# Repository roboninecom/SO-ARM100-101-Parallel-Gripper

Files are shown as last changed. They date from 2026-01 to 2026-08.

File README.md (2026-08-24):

# SO-ARM100/101 Parallel Gripper

<div align="center">

SO-ARM101 Parallel Gripper (https://youtube.com/shorts/bSyXjgNGXZk)

**🎥 [Watch the gripper in action!](https://youtube.com/shorts/bSyXjgNGXZk)**

A lightweight 3D-printed parallel gripper designed by **[Robonine](https://robonine.com)** for the open-source SO-ARM100/101 robotic platform.







---

**Questions? We're here to help!**
📩 Email: [hello@robonine.com](mailto:hello@robonine.com)

</div>

---

## ✨ Key Features

| Feature | Description |
|---|---|
| **120N Gripping Force** | Reliable parallel jaw mechanism |
| **14 mm/s Speed** | Gripper operation speed |
| **84mm Full Stroke** | Wide opening for various objects |
| **0.5mm Repeatability** | High precision positioning |
| **Camera Compatible** | Supports RealSense, Orbbec, USB cameras |
| **3D Printable** | All parts print on standard FDM printers |
| **~$62 Total Cost** | Affordable open-source solution |
| **Easy Assembly** | 30-45 minutes with basic tools |

---

## 📸 Gallery

<div align="center">

### Gripper on SO-ARM101

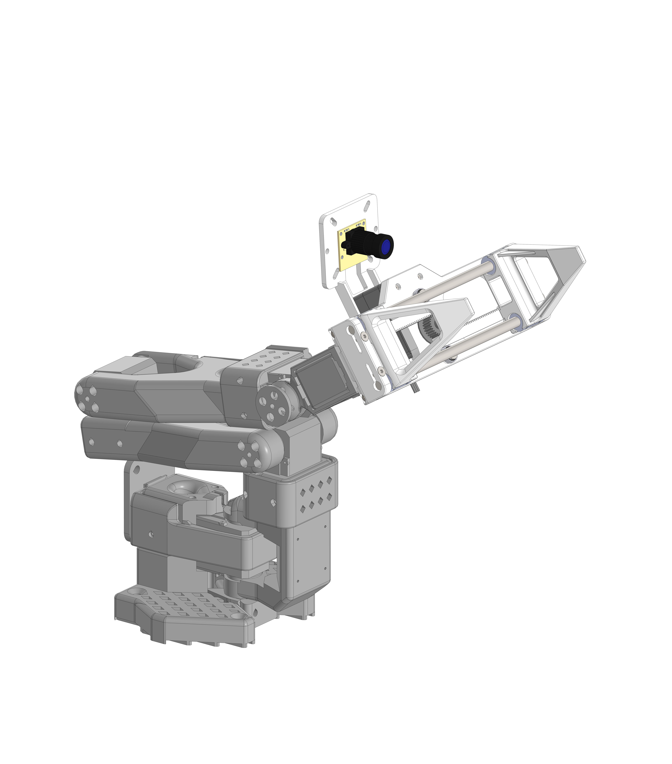
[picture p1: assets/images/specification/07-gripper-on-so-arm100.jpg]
Gripper mounted on SO-ARM101


*Follower gripper integrated with SO-ARM101 robot arm*

### Dimensions

Gripper dimensions

*128 × 109 × 130.5 mm, full stroke 84 mm*

</div>

---

## 📋 Specifications

### Gripper Parameters

| Parameter | Value |
|---|---|
| Maximum gripping force | **120 N** |
| Maximum gripping speed | **14 mm/s** |
| Full stroke | **84 mm** |
| Repeatability | **0.5 mm** |
| Assembly mass (PLA, 30% infill) | **170 g** |
| DOF | **1** |

### Dimensions

| Dimension | Value |
|---|---|
| Width | 128 mm |
| Depth | 130.5 mm |
| Height | 109 mm |

### Servo Parameters (Feetech STS3215)

| Parameter | Value |
|---|---|
| Operating Voltage | 12V |
| Stall torque | 30 kg·cm |
| Speed (no load) | 45 RPM |
| Encoder | Absolute magnetic 12-bit |
| Protocol | RS485/TTL up to 1 Mbps |
| Operating temperature | -20°C ~ 60°C |

---

## 📷 Camera Compatibility

The gripper supports multiple cameras via interchangeable camera holder:

| Camera | Type | Use Case |
|---|---|---|
| IMX335 5MP USB | RGB | Basic vision tasks |
| GC2093 2MP USB | RGB | Budget option |
| Orbbec Gemini 2 | RGB-D | 3D perception |
| RealSense D405 | RGB-D | Close-range depth |
| RealSense D435/D435i | RGB-D | General purpose |
| RealSense D455 | RGB-D | Long-range depth |

<div align="center">

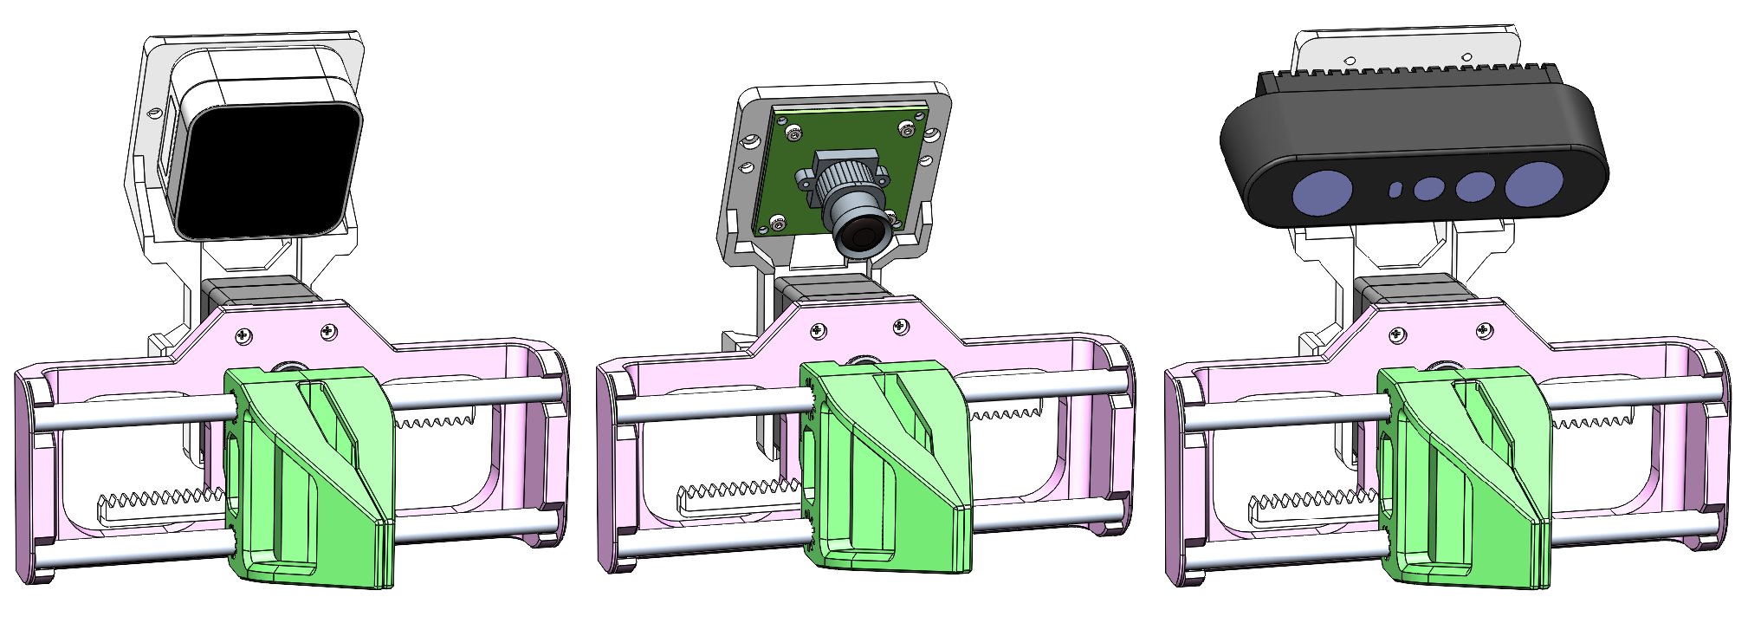
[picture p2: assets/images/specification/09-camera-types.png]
Different cameras mounted on gripper


*RealSense, USB camera module, Orbbec Gemini 2*

</div>

---

## 💰 Bill of Materials

**Total Cost: ~$62** ([Full BOM with Amazon links](docs/bom.md))

| Category | Components | Est. Cost |
|---|---|---|
| Electronics | Feetech STS3215 Servo + Servo Bus Adapter | ~$40 |
| Bearings | MF106ZZ (x2) | ~$2 |
| Aluminium/Carbon Tubes | D6x1×125mm (x2) | ~$4 |
| 3D Printing | 8 parts (~100-150g PLA) | ~$12 |
| Fasteners | M2/M4 screws, M2 nuts, M3 set screws | ~$3 |

---

## 🚀 Quick Start

### 1. Print the Parts (2-4 hours)

Download STL files from [`models/parts/`](models/). Compatible with popular printers like **Bambu Lab A1 mini**, **Prusa MINI+**, and any printer with ≥180×180mm bed.

| Part | Qty | Settings |
|---|:---:|---|
| Main frame (RB9.01.062.010) | 1 | 20% infill |
| Clamp (RB9.01.062.020) | 2 | 20% infill |
| Gear rack (RB9.01.062.030) | 2 | 100% infill |
| Gear (RB9.01.062.040) | 1 | 100% infill |
| Camera holder (RB9.01.060.074) | 1 | 20% infill |
| Holder (RB9.01.060.080) | 1 | 20% infill |
| Camera Spacer (RB9.01.060.090) | 1 | 20% infill |
| D405 holder (RB9.01.060.110) | 1 | 20% infill |

### 2. Order Components (1-2 days)

See [Bill of Materials](docs/bom.md) for direct Amazon links.

### 3. Assemble (30-45 minutes)

Follow the [Assembly Guide](docs/assembly-guide.md) with step-by-step images:

1. Mount gear on servo disc, install this assembly on servo
2. Insert servo cable
3. Using Feetech software move servo to its minimal position (move the slider in the software to the left)
4. Attach gear racks to clamps
5. Inserts the rods into both clamps
6. Install bearings on main frame and fix with srews
7. Snap the rods into the frame
8. Spread the clamps to the extreme positions on the left and right
9. Insert servo and fix it with screws
10. Attach Camera Spacer and UVC camera, fix with 4x screws and nuts M2 (optional)
11. Mount to robot arm (optional)

### 4. Software

```bash
# Configure servo motor if necessary
https://lab.robonine.com/tools/robonine/feetech-bus

# Control gripper
https://lab.robonine.com/tools/robonine/control-robot
```

---

## 📁 Repository Structure

```
├── assets/
│   └── images/
│       ├── assembly/          # Assembly step images
│       └── specification/     # Technical drawings
├── docs/
│   ├── assembly-guide.md                # Step-by-step assembly
│   ├── bom.md                           # Bill of materials with links
│   ├── Parallel gripper by Robo9.pdf    # Gripper product specification
│   ├── quick-start.md                   # Getting started guide
│   ├── SO-ARM101 by Robo9.pdf           # SO-ARM101 product specification
│   └── specifications.md               # Technical specifications
├── models/
│   ├── parts/                                    # Individual STL files
│   └── Follower gripper (165x165 bed size).STL   # Complete assembly (165×165mm bed)
├── community/
│   └── histology-slide-gripper/   # Community variant (CAD, MuJoCo model)
├── simulation/
│   ├── README.md                  # Simulation overview
│   ├── gazebo/                    # Gazebo guide
│   ├── mujoco/                    # MuJoCo guide
│   ├── webots/                    # Webots guide
│   ├── coppeliasim/               # CoppeliaSim guide
│   ├── isaac_sim/                 # Isaac Sim guide
│   └── so_arm_101_description/    # ROS2 package (URDF, launch, Docker)
├── software/
│   └── python/                # Control software
├── examples/                  # Usage examples
├── HARDWARE-LICENSE.txt       # CERN-OHL-P-2.0 (CAD, geometry)
├── SOFTWARE-LICENSE.txt       # Apache-2.0 (code)
├── DOCS-LICENSE.txt           # CC BY 4.0 (docs, images)
├── LICENSING.md               # Which licence covers what
├── NOTICE                     # Third-party attribution
├── REUSE.toml                 # Machine-readable licence map
├── RELICENSING.md             # Record of the 2026 relicensing
└── CONTRIBUTING.md
```

---

## 📖 Documentation

| Document | Description |
|---|---|
| [Quick Start Guide](docs/quick-start.md) | Get running in 30 minutes |
| [Assembly Guide](docs/assembly-guide.md) | Step-by-step with images |
| [Gripper Assembly Guide (PDF)](docs/Assembly%20Guide%20Follower%20Gripper.pdf) | Printable gripper assembly instructions |
| [SO-ARM101 Assembly Guide (PDF)](docs/Assembly%20Guide%20SO-ARM101.pdf) | Full SO-ARM101 arm assembly instructions |
| [Bill of Materials](docs/bom.md) | Parts list with Amazon links |
| [Specifications](docs/specifications.md) | Technical details |
| [3D Models](models/README.md) | Print settings and files |
| [Parallel Gripper Product Spec (PDF)](docs/Parallel%20gripper%20by%20Robo9.pdf) | Parallel gripper product specification by Robo9 |
| [SO-ARM101 Product Spec (PDF)](docs/SO-ARM101%20by%20Robo9.pdf) | SO-ARM101 robot arm product specification by Robo9 |

---

## 🔧 Hardware Requirements

### Electronics
- 1× Feetech STS3215 Servo Motor
- 1× Bus Servo Adapter Board (Waveshare)

### Mechanical
- 2× MF106ZZ Bearings (6×10×3 mm)
- 2× Aluminium/Carbon Tubes D6x1×125 mm

### Fasteners
- 2× M4×8 DIN 7991 screws
- 4x M2x8 DIN 912 screws
- 4× M2 DIN 934 nuts
- 4× M3×4 DIN 913 set screws

### Tools Required
- Phillips head screwdriver (PH1)
- Hex keys M2 (H1.5) and M4 (H2.5)

---

## 🖥️ Simulation

The SO-ARM101 can be simulated in 5 physics engines using a ROS2 description package with a single parameterized URDF. No ROS2 installation required -- Docker handles everything.

<div align="center">

| Gazebo (Ignition Fortress) | MuJoCo |
|:-:|:-:|
| SO-ARM-101 in Gazebo | SO-ARM-101 in MuJoCo |

</div>

| Simulator | Status | Docker |
|---|---|---|
| [Gazebo](simulation/gazebo/README.md) | Ready | `docker compose run gazebo` |
| [MuJoCo](simulation/mujoco/README.md) | Ready | `docker compose run mujoco` |
| [Webots](simulation/webots/README.md) | Unstable | `docker compose run webots` |
| [CoppeliaSim](simulation/coppeliasim/README.md) | Not tested | External simulator |
| [NVIDIA Isaac Sim](simulation/isaac_sim/README.md) | Not tested | External simulator |

**Quick start (Docker):**

```bash
cd simulation/so_arm_101_description
docker compose run gazebo    # or mujoco, webots
```

See the [Simulation Guide](simulation/README.md) for full setup, architecture details, and robot commanding.

---

## 🔬 Community Mods

Variants of the gripper built by the community, each self-contained in [`community/`](community/):

| Mod | Author | Description |
|-----|---|---|
| [Histology Slide Gripper](community/histology-slide-gripper/) | [Michael Viacheslavov](https://github.com/histochemichael) | Clamps for 75 x 25 mm microscope slides and staining dippers/racks, plus an angled Arducam holder for monitoring the grasp. |

<div align="center">

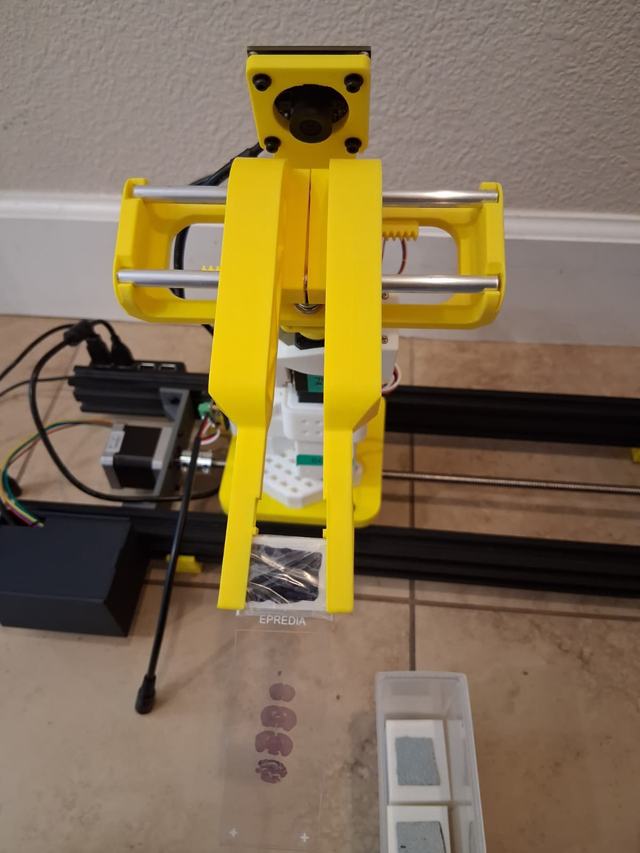
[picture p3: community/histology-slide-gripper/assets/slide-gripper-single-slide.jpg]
Histology slide gripper mod holding a microscope slide


*Histology Slide Gripper mod — click for full description, CAD files, and demo*

</div>

---

## 🤝 Contributing

We welcome contributions! Please feel free to:
- 🐛 Report bugs and issues
- 💡 Suggest new features
- 🔧 Submit pull requests
- 📖 Improve documentation

---

## 📄 License

Copyright (c) 2025 Robonine. This project is multi-licensed — different kinds of
material carry different licences:

| Material | Licence |
|---|---|
| Hardware designs — `models/`, community CAD, gripper meshes | [CERN-OHL-P-2.0](HARDWARE-LICENSE.txt) |
| Software — `software/`, `examples/`, `simulation/`, simulation code in `community/` | [Apache-2.0](SOFTWARE-LICENSE.txt) |
| Documentation and images — `docs/`, `assets/`, all `README.md` | [CC BY 4.0](DOCS-LICENSE.txt) |

See [`LICENSING.md`](LICENSING.md) for the exact file-by-file map and
[`REUSE.toml`](REUSE.toml) for the machine-readable version.

**Not everything here is Robonine's work.** The SO-ARM101 arm meshes are derived
from [TheRobotStudio's upstream project](https://github.com/TheRobotStudio/SO-ARM100)
and remain Apache-2.0; the histology slide gripper was contributed by
[@histochemichael](https://github.com/histochemichael). See [`NOTICE`](NOTICE)
before reusing any mesh.

Releases up to and including `v0.3.1` were published under GPL-3.0 and remain
available under those terms — see [`RELICENSING.md`](RELICENSING.md).

---

## 🔗 Links

- [Feetech STS3215 Servo](https://www.feetechrc.com/525603.html)
- [Waveshare Bus Servo Adapter](https://www.waveshare.com/bus-servo-adapter-a.htm)
- [STServo Python SDK](https://github.com/FEETECH-RC/STServo_SDK_Python)

---

## 👥 Engineering Team

| Name | Role | Contact |
|---|---|---|
| **Boris Kotov** | Software Engineer | [Telegram](https://t.me/bkotov) |
| **Alan Subin** | Design Engineer | [LinkedIn](https://www.linkedin.com/in/alan-subin/) |

---

<div align="center">

**Built for the robotics community by [Robonine](https://robonine.com)** 🤖

**Questions? We're here to help!**
📩 Email: [hello@robonine.com](mailto:hello@robonine.com)

</div>

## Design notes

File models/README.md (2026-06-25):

# 3D Models

This folder contains STL files for the Follower Gripper assembly.

## Complete Assembly

| File | Description | Compatible Printers |
|---|---|---|
| `Follower gripper (165x165 bed size).STL` | Complete gripper parts kit | Printers with bed size > 165×165mm |

### Compatible 3D Printers

- **Bambu Lab A1 mini** (180×180×180mm)
- **Prusa MINI / MINI+** (180×180×180mm)
- **Creality Ender-2 Pro** (165×165×180mm)
- **Anycubic Kobra Neo** (220×220×250mm)
- **Artillery Genius** (220×220×250mm)

*Note: Any printer with bed size ≥165×165mm can print the complete assembly preview.*

## Individual Parts

Located in the `parts/` folder:

| Part Number | File | Qty | Description |
|---|---|:---:|---|
| RB9.01.060.074 | `Camera holder.STL` | 1 | Camera mounting bracket |
| RB9.01.060.080 | `Holder.STL` | 1 | Mounting bracket without camera |
| RB9.01.060.090 | `Camera spacer.STL` | 1 | Spacer for camera |
| RB9.01.060.110 | `D405 holder.STL` | 1 | Holder for D405 camera |
| RB9.01.062.010 | `Main frame.STL` | 1 | Main structural frame |
| RB9.01.062.021 (D6.0) | `Clamp.STL` | 2 | Finger clamps |
| RB9.01.062.021 (D6.1) | `Clamp.STL` | 2 | Finger clamps |
| RB9.01.062.021 (D6.2) | `Clamp.STL` | 2 | Finger clamps |
| RB9.01.062.021 (D6.3) | `Clamp.STL` | 2 | Finger clamps |
| RB9.01.062.031 | `Gear rack.STL` | 2 | Gear racks for linear motion |
| RB9.01.062.040 | `Gear.STL` | 1 | Drive gear |
| RB9.01.062.100 | `Nail.STL` | 2 | Nails |

## Print Settings

| Parameter | Recommended Value |
|---|---|
| Material | PLA / PETG |
| Layer Height | 0.2mm (0.15mm for gears) |
| Infill | 20% (30% for gears) |
| Supports | As needed |
| Walls | 3-4 perimeters |

## Notes

- Print gears with higher infill (100%) for better strength
- Main frame may require supports depending on orientation
- Post-processing: light sanding may be needed for bearing fits
- Individual parts can be printed on any standard FDM printer

## Better rods fit
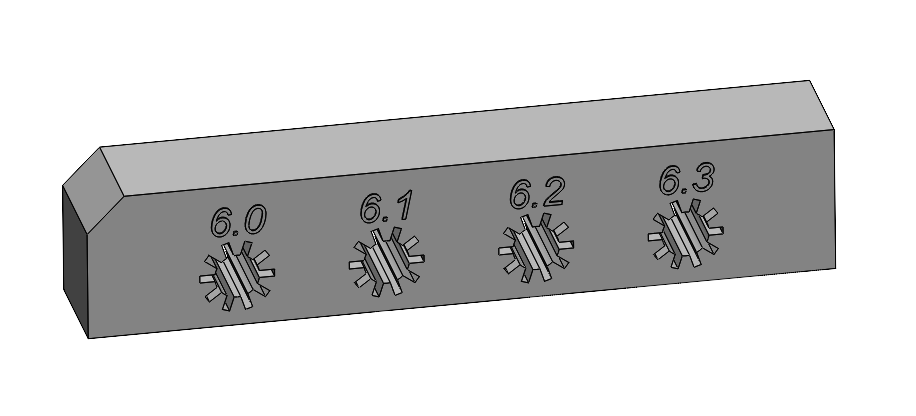
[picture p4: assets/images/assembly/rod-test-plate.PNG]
Test plate


To ensure the rods you purchase fit better into the clamps, you need to use a test piece. Print it and, working from the largest hole to the smallest, select the diameter that allows the rod to fit into the test part without difficulty and with minimal clearance. Then print clamps with the same hole diameter which is mentioned in stl file name (e.g. RB9.01.062.021 (D6.1) if you choose diameter 6.1 mm).

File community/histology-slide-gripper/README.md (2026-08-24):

# Histology Slide Gripper (Community Mod)

A community variant of the SO-ARM100/101 Parallel Gripper by [Michael Viacheslavov](https://github.com/histochemichael), adapted for histology and histotechnology automation: gentle pickup of standard 75 x 25 mm microscope slides, slide staining dippers/racks, and a close camera view of the grasp.

<div align="center">

Histology slide gripper demo

*SO-ARM100/101 parallel gripper using the custom clamps to handle microscope slides and a staining dipper/rack.*

</div>

## What Changed vs. the Base Gripper

| Addition | Description |
|---|---|
| Microscope slide clamps | Long, flat clamp geometry supports direct pickup of standard 75 x 25 mm microscope slides. |
| Slide rack/dipper handling | Clamp spacing and tips engage slide staining dippers/racks like the Medicus Health slide staining dipper linked below. |
| Angled Arducam holder | A printable holder aims an Arducam global-shutter USB camera at the gripper jaws for close-up monitoring of slide and rack pickup. |
| Complete assembly CAD | A full printable STL and editable STEP assembly are in [`cad/`](cad/). |

## Gallery

<div align="center">

| Single slide pickup | Staining dipper/rack pickup | Arducam holder view |
|:-:|:-:|:-:|
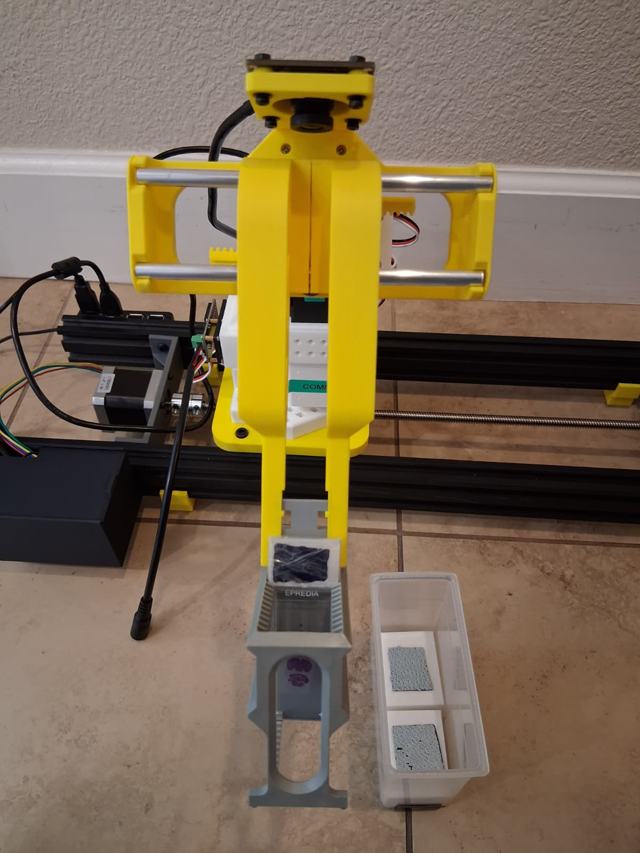
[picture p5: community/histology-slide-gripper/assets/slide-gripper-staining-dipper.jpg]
Clamp aligned with slide staining dipper
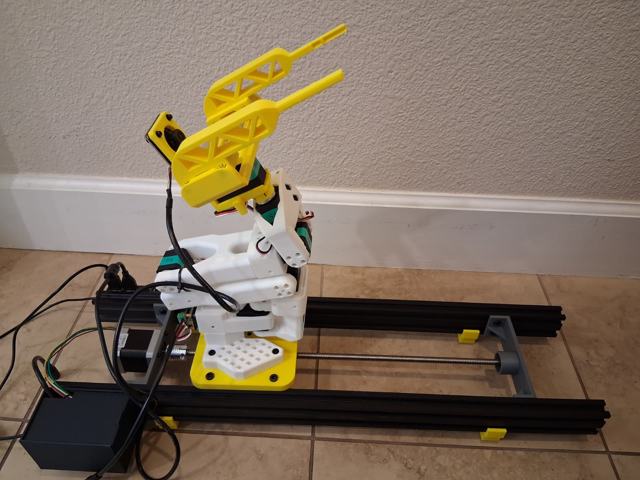
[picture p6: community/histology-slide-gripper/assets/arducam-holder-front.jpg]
Arducam holder above the gripper jaws
| Clamp holding a microscope slide |  |  |

| Front view | Jaw geometry | Isometric assembly |
|:-:|:-:|:-:|
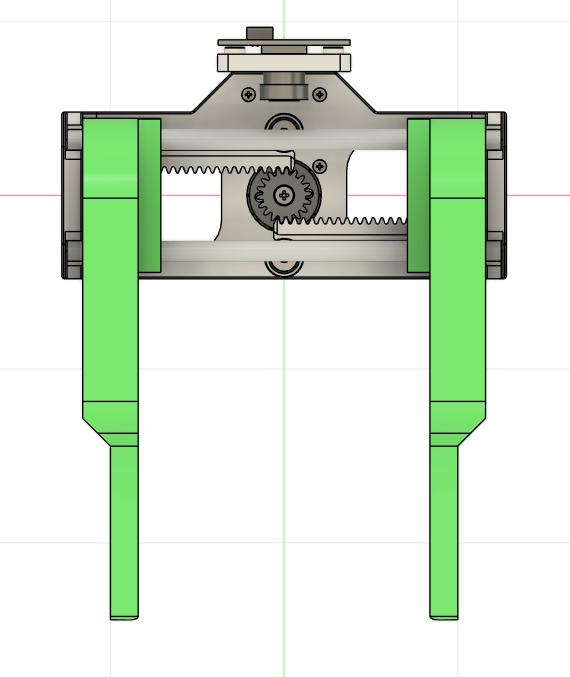
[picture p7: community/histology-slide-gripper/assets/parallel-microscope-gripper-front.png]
Front CAD view of the microscope slide gripper mod
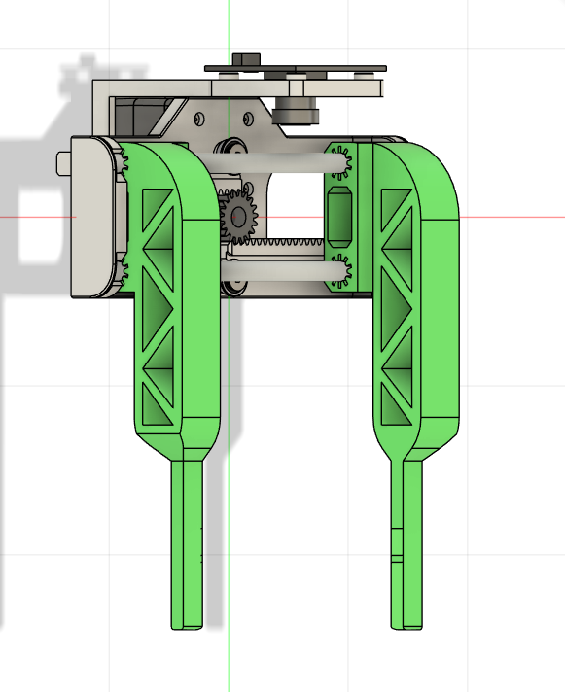
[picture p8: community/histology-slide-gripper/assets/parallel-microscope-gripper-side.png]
Angled CAD view showing the microscope slide jaw geometry
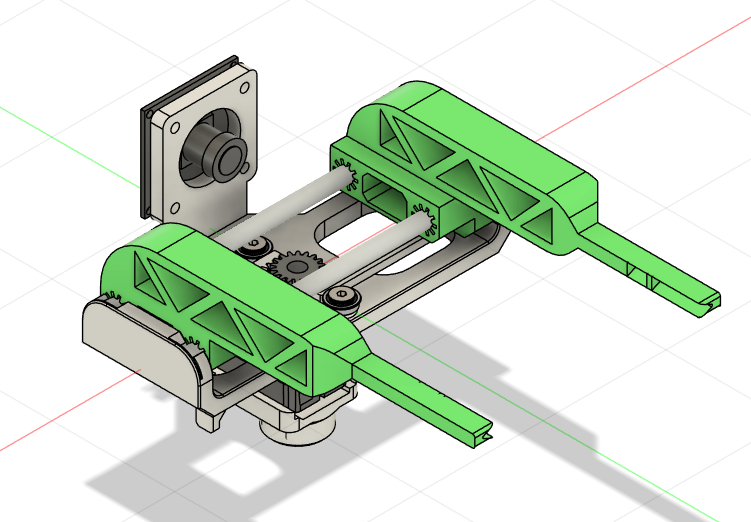
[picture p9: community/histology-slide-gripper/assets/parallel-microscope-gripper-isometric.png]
Isometric CAD view of the full microscope slide gripper assembly
|  |  |  |

</div>

## CAD Files

| File | Format | Use |
|---|---|-----|
| [`cad/the-parallel-microscope-slide-gripper.stl`](cad/the-parallel-microscope-slide-gripper.stl) | STL | Printable full assembly for the microscope slide gripper mod. |
| [`cad/the-parallel-microscope-slide-gripper.step`](cad/the-parallel-microscope-slide-gripper.step) | STEP | Editable CAD source for the full assembly. |

## Add-on Bill of Materials

These items are specific to the slide/rack workflow and are not part of the base gripper [BOM](../../docs/bom.md).

| Component | Qty | Notes | Link |
|---|:---:|---|---|
| Arducam 100fps Mono Global Shutter USB Camera, OV9281 | 1 | Camera used with the angled holder to watch slide and rack pickup near the jaws. | [Amazon UK](https://www.amazon.co.uk/Arducam-Shutter-Distortion-Computer-Raspberry/dp/B0FXWWF55X) |
| Slide Staining Plastic Dipper with Handle | 1+ | Reference staining dipper/rack target; designed for standard 75 x 25 mm slides. | [Medicus Health](https://www.medicus-health.com/slide-staining-dipper.html) |
| Parallel microscope slide gripper assembly | 1 | Print `the-parallel-microscope-slide-gripper.stl`; STEP file is included for edits. | [`cad/`](cad/) |

## MuJoCo Simulation

<div align="center">

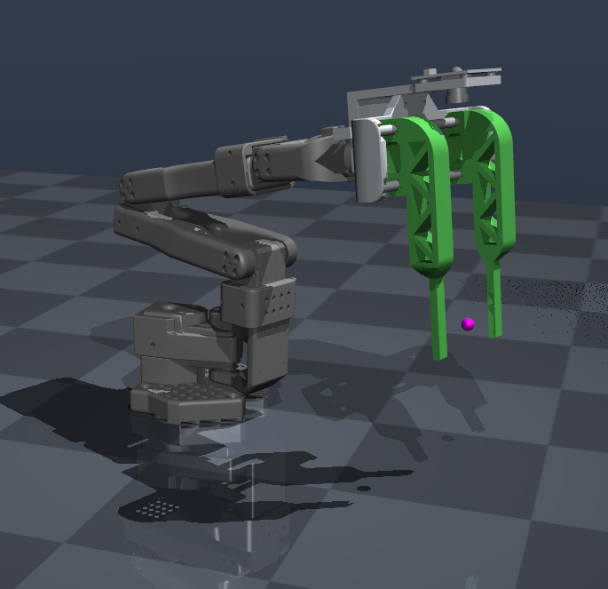
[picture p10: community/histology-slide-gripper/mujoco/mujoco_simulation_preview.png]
SO-ARM101 histology slide gripper running in MuJoCo


*SO-ARM101 with the histology slide gripper mounted and running in MuJoCo.*

</div>

A self-contained MuJoCo 3.4.0 model is available in [`mujoco/`](mujoco/). It includes the full SO-ARM101 model, gripper meshes, a standalone gripper testbench, build scripts, and a headless grasp-and-lift check.

From the repository root:

```bash
conda activate lerobot
cd community/histology-slide-gripper/mujoco
python -m pip install -r requirements.txt
python view.py
```

Use the `sg_grip` control in the MuJoCo viewer to open and close the jaws. See the [simulation README](mujoco/README.md) for model details, controls, validation, and rebuilding instructions.

## Notes

- The gripper fingers are intended for standard 75 x 25 mm microscope slides and slide staining dippers/racks.
- The assembly keeps the camera view aimed toward the gripper jaws so the camera can observe slide and rack pickup.
- Test with non-critical slides first and tune print material, infill, and gripper force for your workflow.

## Links

- 🎥 [Demo: slide and staining rack pickup (LinkedIn)](https://www.linkedin.com/posts/michael-viacheslavov_histology-histotechnology-robotics-ugcPost-7482570199859240960-Gqpw/)

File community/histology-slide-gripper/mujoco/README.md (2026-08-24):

# Microscope Slide Gripper in MuJoCo

The SO-ARM101 with the histology slide parallel gripper, exported from Fusion and mounted in place of the stock Robo9 clamps.

Tested with `mujoco` 3.4.0 in the `lerobot` conda environment. No ROS 2 or Docker is required.

```bash
conda activate lerobot
cd community/histology-slide-gripper/mujoco
python -m pip install -r requirements.txt
python view.py                      # full arm + slide gripper
python view.py scene_gripper.xml    # gripper alone on a testbench
python test_grasp.py                # headless grasp-and-lift check -> grasp_check.png
```

## MuJoCo simulation preview

SO-ARM101 histology slide gripper running in MuJoCo

This scene shows the SO-ARM101 with the histology slide parallel gripper mounted on
the wrist, using the same MuJoCo model launched by:

```bash
conda activate lerobot
cd community/histology-slide-gripper/mujoco
python view.py
```

## What is modelled

| Link | Source | Mass |
|---|---|---|
| `slide_gripper_base` | main frame, STS3215, guide rods, bearings, camera holder, Arducam OV9281 | 0.20 kg |
| `sg_jaw_right` / `sg_jaw_left` | RB9.01.062.020 clamp + RB9.01.062.030 rack (m0.8) | 0.035 kg each |
| `sg_pinion` | RB9.01.062.040 involute gear, 18 T, 0.8 module | 0.008 kg |

Kinematics taken from the as-built joints in the Fusion assembly
(`Slide_Jaw_Right`, `Slide_Jaw_Left`, `Drive_Pinion`), which are self-consistent:
the 18 T / 0.8 module pinion has a 7.2 mm pitch radius, and 7.2 mm x 4.9306 rad =
**35.5 mm** of rack travel per jaw — exactly the slider limits in the CAD.

## Control

One actuator, `sg_grip`, commanded in **metres of jaw travel**:

| `ctrl` | jaw travel | aperture between the blade faces |
|---|---|---|
| `0.0` | 0 mm | **84 mm** (fully open) |
| `0.0295` | 29.5 mm | 25 mm (a microscope slide) |
| `0.0355` | 35.5 mm | **13 mm** (fully closed) |

Both jaws are driven from the single pinion, so `sg_jaw_left_joint` and
`sg_pinion_joint` are slaved to `sg_jaw_right_joint` by `<equality>` constraints —
the gear visibly turns with the jaws. Command *past* the object to get squeeze:
closing onto a 25 mm object with `ctrl=0.0355` gives about 4.7 N at the pads.

The five arm joints keep their URDF names (`base_link_to_link1` ... `link4_to_link5`).

## Collision geometry

Mesh geoms are **visual only** (`contype=0`), because MuJoCo convex-hulls meshes and
the hull of an L-shaped jaw fills the gap you are trying to grip with. Contact is
carried by boxes on the two gripping surfaces of each jaw (group 3, hidden in the
renders):

- `sg_pad_*` — the 30 mm slide blade, CAD x 42–50, z 26–31
- `sg_mid_*` — the wider mid-section, CAD x 42–58, z 18.5–38.5

The TCP site `sg_tcp` sits between the blades; `sg_camera` is the Arducam optical frame.

## Files

- `so101_slide_gripper.xml` — the full robot (generated by `build_full.py`)
- `scene_gripper.xml` — gripper alone, with a lift axis for testing
- `gripper_assets.xml` / `gripper_body.xml` / `gripper_actuation.xml` — the gripper,
  as includes usable from both degree- and radian-unit models
- `meshes/{base,jaw_right,jaw_left,pinion}.stl` — exported from Fusion in **assembly
  coordinates**, so every part is already in its correct place (no per-part origins to chase)
- `meshes/arm/` — arm meshes from the Robo9 repo
- `build_arm.py` — strips xacro from `so_101.urdf.xacro`, drops the stock clamps, compiles to MJCF
- `build_full.py` — grafts the gripper onto `link5`; **edit `MOUNT_POS`/`MOUNT_QUAT` here**

## How the gripper was located on the wrist

`link5_1.stl` in the Robo9 repo is not just the wrist — it contains the entire stock
gripper (frame, guide rods, camera). So it is the part the slide-gripper design replaces, and
`build_full.py` deletes its mesh and drops its mass from 0.556 kg to 0.08 kg.

The mount pose was solved, not guessed: `base.stl` was fitted against
`link5_1.stl` over the geometry they share (main frame + guide rods) by searching all
24 axis-aligned rotations and scoring nearest-neighbour distance. Best fit is
**+90 deg about X** (CAD +Y -> link5 +Z, CAD +Z -> link5 -Y) with a 2.0 mm median
residual — the slide clamps hang perpendicular to Robo9's pointed clamps, matching
the Fusion assembly.

## Stability

The model settles to `max|qvel| = 0` and stays there. If you ever see it shake, the
first thing to check is stray contacts (`ncon` in the viewer's info panel should be 0
with the arm at rest). Three things were needed:

1. **`<exclude body1="world" body2="link1_1"/>`** - the real fix. The URDF importer
   merges `base_link` into `worldbody`, and MuJoCo skips parent/child collisions
   *except* when the parent is the world body. So the base mesh and link1 mesh
   interpenetrated at the shoulder, producing a permanent contact that pinned the yaw
   actuator at its +-1.5 N.m limit. This alone took settled `|qvel|` from 4.78 to 0.
2. `sg_pinion_joint` armature 1e-6 -> **1e-4**. A joint slaved by a stiff equality with
   almost no inertia chatters (it was peaking at 12 rad/s).
3. Equality `solref` 0.002 -> **0.01**. A constraint time constant equal to the timestep
   is too stiff to solve cleanly; this also made the pinion land exactly on -282.5 deg
   instead of -280 deg.

## Caveats

- **Masses are assumed, not measured.** Fusion reports every body as steel (the jaws
  come out at 221 g each); the values above are PLA-and-hardware estimates. If you
  assign real materials in Fusion, update the `mass=` attributes in `gripper_body.xml`.
- Inertia is derived by MuJoCo from the mesh shape plus that mass, not from Fusion's tensor.
- The arm's joint limits, damping and friction are inherited from the repo's URDF and
  have not been re-tuned.
- **The arm's link masses are steel-density too**, the same defect as the gripper: the
  repo URDF totals **2.81 kg** against roughly 1 kg for a real SO-101, and `link2_to_link3`
  needs 1.91 N.m to hold itself up against a 1.5 N.m actuator limit, so it sags. This does
  not cause shaking (see above) but it does make the arm behave like a much heavier
  machine. Scaling every arm link mass and `diaginertia` by ~0.36 brings the total to
  1.19 kg and clears the saturation; the real STS3215 also stalls nearer 2.9 N.m than the
  URDF's conservative 1.5.
- The 2 mm alignment residual is real: the "Main frame_125 follower" is not identical
  to the frame baked into `link5_1.stl`.
- `sg_pinion_joint` is cosmetic - it carries no load, because the two racks are coupled
  to each other directly. It exists so the gear turns the right way on screen.

## Driving it in the MuJoCo viewer

Use the **`sg_grip` slider in the Control panel**. The sliders in the *Joint* panel
write `qpos` directly and bypass the equality constraints, so dragging those (especially
while paused) desynchronises the jaws from the pinion. Pressing Run re-converges it.

## Re-exporting after a CAD change

The export ran through the Fusion MCP connection: it walks every occurrence, groups
bodies into the four rigid links, and writes binary STLs in assembly coordinates
(mm). Re-export with the Fusion design open to refresh the meshes in
place — nothing else needs to change unless you move a joint.

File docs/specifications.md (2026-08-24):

# SO ARM 100/101 Parallel Follower Gripper

## Overview

Lightweight 3D-printed end-effector designed by **Robonine** for the open-source teleoperating robotic platform SO ARM 100/101. The mechanism provides reliable parallel jaw motion and sufficient gripping force for a broad range of educational and experimental applications.

Follower gripper mounted on SO-ARM100

*Follower gripper mounted on SO-ARM100 robot arm*

## Key Features

- Open-source design
- BOM cost for one gripper: ~$62
- Can be printed during one cycle on a consumer-grade FDM 3D printer
- Compatible with popular video cameras:
  - Orbbec Gemini 2
  - RealSense D405, D435/D435i, D455
  - GC2093 2MP USB Camera Module
  - IMX335 5MP USB Camera

---

## Dimensions

### 3D Overview

Gripper dimensions — isometric view

*Isometric view showing overall dimensions: 128 × 109 × 130.5 mm, full stroke 84 mm*

| Dimension | Value |
|---|---|
| Width | 128 mm |
| Depth | 130.5 mm |
| Height | 109 mm |
| Full stroke | 84 mm |

---

## Mounting Interface

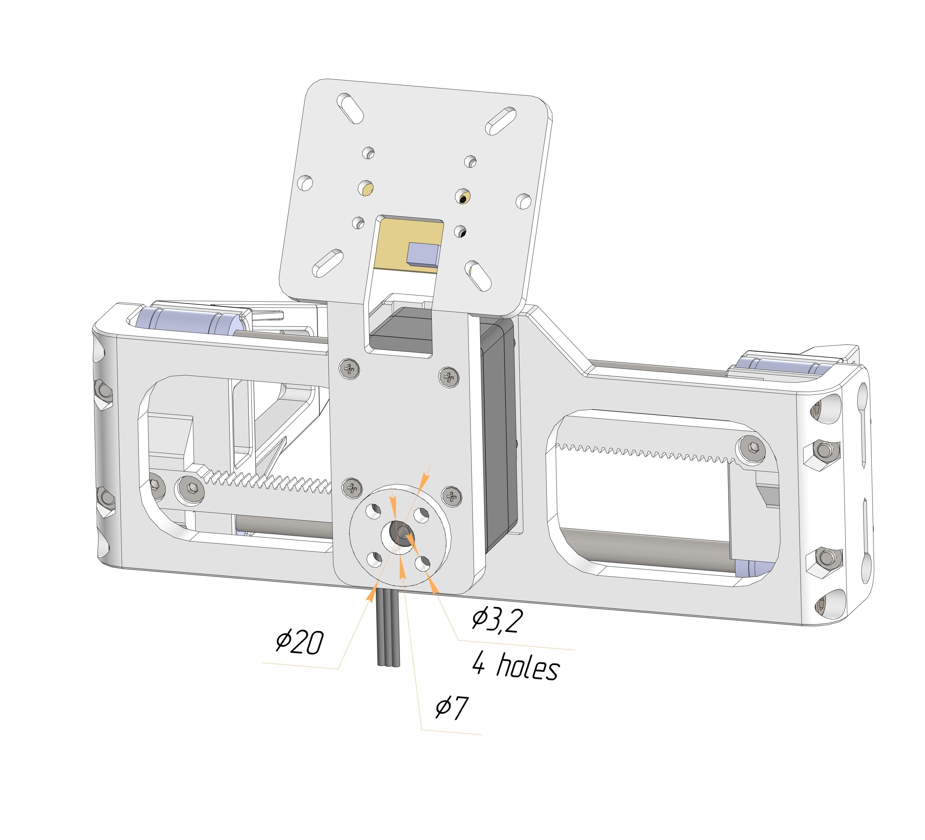
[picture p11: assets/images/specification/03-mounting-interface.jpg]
Mounting interface dimensions


*Mounting flange with hole pattern for robot arm attachment*

| Feature | Dimension |
|---|---|
| Mounting flange diameter | Ø20 mm |
| Center bore | Ø7 mm |
| Mounting holes | 4x Ø3.2 mm |

---

## Gripper Parameters

| Parameter | Follower Gripper |
|---|---|
| Assembly mass (PLA, 30% infill) | 170 g |
| Maximum gripping force | 120 N |
| Maximum gripping speed | 14 mm/s |
| Full stroke | 84 mm |
| Repeatability | 0.5 mm |
| DOF | 1 |

---

## Technical Specifications

### Materials & Construction

| Component | Specification |
|---|---|
| Primary material | PETG / PLA |
| Transmission | Rack and pinion |
| Guides | Round aluminium/carbon tubes (Ø6 mm) |
| Driver | Feetech servo actuator STS3215 |

### Servo Parameters (Feetech STS3215)

| Parameter | Value |
|---|---|
| Operating Voltage Range | 12V |
| Speed (no load) | 45 RPM |
| Running current (no load) | 180 mA |
| Stall torque (at locked) | 30 kg·cm |
| Stall current (at locked) | 2.7 A |
| Idle current (at stopped) | 30 mA |
| Rated torque | 10 kg·cm |
| Rated current | 900 mA |
| Terminal resistance | 1 Ω |
| Operating temperature | -20°C ~ 60°C |
| Encoder type | Absolute magnetic 12-bit |
| Control protocol | RS485/TTL up to 1 Mbps |
| Electronic protection | Against high voltage, current, load, and temperature |

---

## Camera Compatibility

The Follower gripper is compatible with various cameras via interchangeable camera holder.

Different cameras mounted on gripper

*Different cameras mounted on gripper (left to right): RealSense, USB camera module, Orbbec Gemini 2*

### Supported Cameras

| Camera | Type | Notes |
|---|---|---|
| IMX335 5MP USB | RGB | Compact, low-cost |
| GC2093 2MP USB | RGB | Budget option |
| Orbbec Gemini 2 | RGB-D | Depth sensing |
| RealSense D405 | RGB-D | Close-range depth |
| RealSense D435/D435i | RGB-D | General purpose |
| RealSense D455 | RGB-D | Long-range depth |

---

## Supplied Resources

- Complete set of STL files for 3D printing
- Assembly guide
- Drawings with mounting dimensions
- URDF file for robotic simulators

---

## Integration

The gripper can be independently integrated into numerous robotic systems thanks to its convenient and simple installation via the standard mounting flange.

### Mounting Requirements

- 4x M3 screws for flange attachment
- Compatible with SO-ARM100/101 robot arm
- Custom adapter plates available for other robot arms

### Communication

- Serial connection via TTL or RS485
- Baud rate: Up to 1 Mbps
- Protocol: Feetech STS protocol

---

## Product Specification Documents

- [Parallel Gripper Product Specification (PDF)](Parallel%20gripper%20by%20Robo9.pdf) — Full product specification for the parallel gripper by Robo9
- [SO-ARM101 Product Specification (PDF)](SO-ARM101%20by%20Robo9.pdf) — Full product specification for the SO-ARM101 robot arm by Robo9

---

*Specifications subject to change based on actual implementation and testing*

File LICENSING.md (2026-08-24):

# Licensing

Copyright (c) 2025 Robonine

This project releases different kinds of material under different licences.
Every file in this repository is covered by exactly one of them.

| Material | Licence | Text |
|---|---|---|
| Hardware designs (CAD, manufacturable geometry) | CERN-OHL-P-2.0 | [`HARDWARE-LICENSE.txt`](HARDWARE-LICENSE.txt) |
| Software (code, configuration, CI, robot descriptions) | Apache-2.0 | [`SOFTWARE-LICENSE.txt`](SOFTWARE-LICENSE.txt) |
| Documentation, renders and photographs | CC-BY-4.0 | [`DOCS-LICENSE.txt`](DOCS-LICENSE.txt) |

The machine-readable version of this map is [`REUSE.toml`](REUSE.toml), which
assigns a licence to every file by path and is enforced by `reuse lint` in
pre-commit and CI. `LICENSES/` holds the same three texts under their SPDX
names, as the REUSE Specification requires.

**Some material here is not Robonine's.** See [`NOTICE`](NOTICE) for attribution
and section 4 below for the precise file list.

---

## 1. Hardware — CERN-OHL-P-2.0

```
models/                                             *.STEP, *.STL
models/parts/                                       *.STL
community/histology-slide-gripper/cad/              *.step, *.stl
community/histology-slide-gripper/mujoco/meshes/    base.stl, jaw_left.stl,
                                                    jaw_right.stl, pinion.stl
simulation/so_arm_101_description/meshes/visual/    clamp_1.stl, clamp_2.stl
simulation/so_arm_101_description/meshes/collision/ clamp_1.stl, clamp_2.stl
```

`README.md` files inside these directories are documentation and fall under
CC-BY-4.0, not CERN-OHL-P-2.0.

Recommended notice when reusing this hardware:

```
Copyright (c) 2025 Robonine

This source describes Open Hardware and is licensed under the CERN-OHL-P v2.
You may redistribute and modify this source and make products using it under
the terms of the CERN-OHL-P v2 (https://ohwr.org/cern_ohl_p_v2.txt).

This source is distributed WITHOUT ANY EXPRESS OR IMPLIED WARRANTY, INCLUDING
OF MERCHANTABILITY, SATISFACTORY QUALITY AND FITNESS FOR A PARTICULAR PURPOSE.

SPDX-License-Identifier: CERN-OHL-P-2.0
```

## 2. Software — Apache-2.0

```
software/python/                    examples/                 .github/workflows/
.pre-commit-config.yaml             .gitignore
simulation/so_arm_101_description/  package.xml, setup.py, setup.cfg, Dockerfile,
                                    docker-compose.yaml, .dockerignore,
                                    urdf/, config/, launch/, scripts/, test/,
                                    docker/, worlds/, so_arm_101_description/
community/histology-slide-gripper/mujoco/   *.py, *.xml, *.urdf, *.xacro,
                                            requirements.txt
```

The robot description under `urdf/` is licensed as software rather than as
hardware: it encodes kinematics, inertias and joint limits for the whole arm,
much of which describes upstream SO-ARM101 geometry that Robonine does not own
and therefore cannot place under CERN-OHL-P-2.0. The manufacturable gripper
design itself lives in `models/` and is covered by section 1.

## 3. Documentation — CC-BY-4.0

```
README.md, CONTRIBUTING.md, LICENSING.md, RELICENSING.md
docs/                   *.md, *.pdf
assets/images/          *.png, *.PNG, *.jpg
every other README.md in the repository
community/histology-slide-gripper/assets/   *.png, *.jpg, *.gif
```

Attribution for reuse: "Robonine — SO-ARM100/101 Parallel Gripper,
https://github.com/roboninecom/SO-ARM100-101-Parallel-Gripper, CC BY 4.0".

## 4. Mixed and third-party material

The following are **not** covered by the Robonine copyright above. They are
derived from the upstream SO-ARM100/SO-ARM101 project by TheRobotStudio and are
redistributed under Apache-2.0. See [`NOTICE`](NOTICE).

```
simulation/so_arm_101_description/meshes/visual/     base_link.stl, link1_1.stl,
                                                     link2_1.stl, link3_1.stl,
                                                     link4_1.stl
simulation/so_arm_101_description/meshes/collision/  convex hulls of the above,
                                                     generated by
                                                     scripts/generate_collision_meshes.py
```

`link5_1.stl` (in both `visual/` and `collision/`) is a single mesh that fuses
upstream SO-ARM101 wrist geometry with Robonine's `RB9.01.062.010 Main frame`.
Until it is re-exported as two separate meshes, the whole file is distributed
under Apache-2.0: Robonine cannot grant CERN-OHL-P-2.0 over geometry it does not
own, and is free to license its own portion under Apache-2.0. The same geometry
is available separately under CERN-OHL-P-2.0 as
`models/parts/RB9.01.062.010 Main frame.STL`.

`community/histology-slide-gripper/mujoco/meshes/arm/*.stl` are byte-identical
copies of `simulation/so_arm_101_description/meshes/visual/*.stl` and inherit
their licensing from there — so six of those eight files are upstream material,
not Robonine's work.

`community/histology-slide-gripper/` was contributed by Michael Viacheslavov
([@histochemichael](https://github.com/histochemichael)) and is licensed under
the same three-way split; copyright is held by its author.

See [`simulation/so_arm_101_description/meshes/LICENSE.md`](simulation/so_arm_101_description/meshes/LICENSE.md)
for the per-file breakdown of that directory.

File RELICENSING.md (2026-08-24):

# Relicensing record

This file records how and why this project moved off GPL-3.0, and the agreement
of its contributors. It exists so the licence history is auditable without
digging through git.

**Status: IN PROGRESS.** This change must not be merged until every ack below is
recorded.

## What changed

| Material | Before | After |
|---|---|---|
| Hardware / CAD | GPL-3.0-only | CERN-OHL-P-2.0 |
| Software | GPL-3.0-only | Apache-2.0 |
| Documentation and images | GPL-3.0-only | CC BY 4.0 |

Copyright holder: **Robonine**. See `LICENSING.md` for the file-by-file map,
`REUSE.toml` for the machine-readable version, and `NOTICE` for third-party
attribution.

## Why

GPL-3.0 is written for software. Its definitions — "source code", "object
code", "Corresponding Source" — do not map cleanly onto a physical object, so
for the CAD portion of this project it was never clear what actually triggered
the licence's obligations. CERN-OHL-P-2.0 is written for hardware and says
plainly what a Product, Covered Source and Available Component are.

The permissive choice is deliberate. It trades away protection against closed
forks of the gripper in exchange for zero friction for integrators, and for
compatibility with the upstream SO-ARM100/101 project and the wider
LeRobot/ROS ecosystem, which are Apache-2.0 throughout.

## Licence history

| Commit | Date | What |
|---|---|---|
| `00fae7b` | 2025-06-27 | Repository created. `LICENSE` was **MIT** (21 lines). |
| `64d3f01` | 2025-07-01 | `LICENSE` replaced with GPL-3.0 (674 lines). |
| `d37855a` | 2025-07-06 | `README.md` updated from MIT to GPL-3.0. |
| this change | — | Three-way split described above. |

`CONTRIBUTING.md` and `software/python/gripper_control.py` were **never**
updated in 2025 and continued to state MIT. That was an oversight, not
deliberate dual-licensing.

The consequence matters: every external contributor joined *after* the GPL flip,
in a repository whose `CONTRIBUTING.md` still told them *"By contributing, you
agree that your contributions will be licensed under the MIT License."* The
licence they were actually offered was more permissive than GPL-3.0. This change
brings the repository into line with what contributors were told, not against
it. We are nonetheless asking each of them explicitly rather than relying on
that.

## Contributor agreement

| Contributor | Commits | Scope | Ack |
|---|---|---|---|
| Robonine (Nikita Bragin — also `brnikita`, `branikita`) | 76 | Owner | n/a |
| AlanWorkaholic (Alan Subin) | 44 | `models/`, `models/parts/`, `assets/images/`, `docs/` | Work made under contract with IP assignment to Robonine; ack requested as a courtesy |
| histochemichael (Michael Viacheslavov) | 3 + files uploaded on his behalf | `community/histology-slide-gripper/` | _pending_ |
| Vladimir Osipov | 1 | `README.md` dead-link fix | _pending_ |
| Syed Azhar Hussain Quadri | 1 | `software/python/gripper_control.py` | _pending_ |

Relicensing issue: _to be filled in_

### Authorship notes

- Commits authored as `Codex <codex@openai.com>` were made by Nikita Bragin on
  behalf of Robonine. They are not third-party contributions.
- The community variant's CAD and images
  (`community/histology-slide-gripper/cad/*`, `assets/*`) were **committed by
  Robonine on Michael Viacheslavov's behalf** — commits `537f347` and `b4698e7`
  are authored as `Codex`. Authorship of those files belongs to Michael; git
  metadata does not reflect that, which is why it is written down here.

## Decisions on the record

**`link5_1.stl` is a fused mesh.** It combines the upstream SO-ARM101 wrist with
Robonine's `RB9.01.062.010 Main frame` in a single body. The parts are not
separable within the file, so the whole file is distributed under Apache-2.0:
Robonine cannot grant CERN-OHL-P-2.0 over geometry it does not own, and is free
to license its own portion under Apache-2.0. Re-exporting it as two meshes would
let each part carry its proper licence; that is left as future work.

**Notices for binary files.** CERN-OHL-P-2.0 expects licence notices to be
retained in the Source. Binary STL and STEP files cannot carry them, and
`.pre-commit-config.yaml` deliberately excludes those formats from text hooks.
`REUSE.toml` is how this project discharges that obligation: it assigns
copyright and licence to every file by path, and `reuse lint` enforces that
nothing is left uncovered.

Directory-level notices were deliberately kept to a minimum — only where they
carry information the root map does not. Two survive:
`simulation/so_arm_101_description/meshes/LICENSE.md`, because that directory
mixes Robonine and upstream geometry and someone copying a mesh out needs to see
that; and `simulation/so_arm_101_description/LICENSE.md`, because that ROS
package is distributed standalone and has to be self-describing.

**Licence texts exist in two places.** `LICENSES/` is where the REUSE
Specification requires them; `HARDWARE-LICENSE.txt`, `SOFTWARE-LICENSE.txt` and
`DOCS-LICENSE.txt` at the root are what GitHub's licence detection reads, so the
repository shows all three licences rather than none.

**`software/FD.exe` was removed.** It is Feetech's proprietary "FT SCServo Debug"
tool, committed in `7783073` with no licence grant, and was covered by the
project's blanket GPL-3.0 claim — which was incorrect. `docs/assembly-guide.md`
now points to Feetech's own download and to an open-source alternative.

**Git history was not rewritten.** `FD.exe` remains in history and in the source
archives of releases `v0.1.0` through `v0.3.1`. Rewriting would invalidate every
clone, fork and commit SHA referenced from open upstream pull requests, which is
not worth it for a tool Feetech distributes free of charge.

**`ament_copyright` was dropped** from `package.xml`. It was declared but never
wired up or run. It checks for licence headers inside source files, which
conflicts with this project's approach of declaring licences in `REUSE.toml` —
forced on us by the fact that most files here are binaries. `reuse lint` covers
every file in the repository, not just the dozen Python files inside the ROS
package.

## Releases

This does not retroactively change releases `v0.1.0` through `v0.3.1`, which
remain available under GPL-3.0-only.

---

Prepared by the project maintainers. This is a record of decisions, not legal
advice.

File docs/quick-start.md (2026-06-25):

# Quick Start Guide

Get your Follower Gripper for SO-ARM101 up and running!

SO-ARM101 Parallel Gripper (https://youtube.com/shorts/bSyXjgNGXZk)

*Click the image to [watch the gripper in action](https://youtube.com/shorts/bSyXjgNGXZk)!*

## What You'll Need

### Hardware
- [ ] All 3D printed parts (see [3D Models](../models/))
- [ ] Electronic components (see [BOM](bom.md))
- [ ] Mechanical components (bearings, rods, fasteners)
- [ ] Tools: Phillips screwdriver PH1, Hex keys M2 (H1.5) and M4 (H2.5)

### Software
- [ ] Python 3.6+ installed
- [ ] STServo SDK downloaded
- [ ] Serial communication interface

---

## Step 1: 3D Print the Parts (2-4 hours)

1. Download STL files from `models/parts/`
2. Print with recommended settings:
   - Layer height: 0.2mm
   - Infill: 20% (frame/clamps), 100% (gears)
   - Material: PLA or PETG
3. Remove supports

Test plate

To ensure the rods you purchase fit better into the clamps, you need to use a test piece. Print it and, working from the largest hole to the smallest, select the diameter that allows the rod to fit into the test part without difficulty and with minimal clearance. Then print clamps with the same hole diameter which is mentioned in stl file name (e.g. RB9.01.062.021 (D6.1) if you choose diameter 6.1 mm).

**Compatible 3D Printers** (180×180mm+ bed):
- Bambu Lab A1 mini
- Prusa MINI / MINI+
- Anycubic Kobra Neo
- Any printer with bed ≥180×180mm

**Parts to print:**
- 1x Main frame (RB9.01.062.010)
- 2x Clamp (RB9.01.062.020)
- 2x Gear rack (RB9.01.062.030)
- 1x Gear (RB9.01.062.040)
- 1x Camera holder (RB9.01.060.074)
- 1x Holder (RB9.01.060.080)
- 1x Camera Spacer (RB9.01.060.090)

---

## Step 2: Gather Components (1-2 days shipping)

Order parts from the [Bill of Materials](bom.md):

| Component | Qty | Est. Cost |
|---|:---:|---|
| Feetech STS3215 servo | 1 | ~$29 |
| Bus Servo Adapter Board | 1 | ~$11 |
| MF106ZZ bearings (10x6x3mm) | 2 | ~$2 |
| Aluminium/carbon tubes D6x1x125mm | 2 | ~$4 |
| 3d printing PLA| 8 parts | ~$12 |
| Fasteners (M2/M4 screws/nuts) | various | ~$3 |

**Total estimated cost: ~$62**

---

## Step 3: Assembly (30-45 minutes)

Follow the detailed [Assembly Guide](assembly-guide.md):

1. Insert servo cable
2. Using Feetech software move servo to its minimal position (move the slider in the software to the left)
3. Attach gear racks to clamps
4. Inserts the rods into both clamps
5. Install bearings on main frame and fix with srews
6. Snap the rods into the frame
7. Spread the clamps to the extreme positions on the left and right
8. Insert servo and fix it with screws
9. Attach Camera Spacer and UVC camera, fix with 4x screws and nuts M2 (optional)
10. Mount to robot arm (optional)

---

## Step 4: Software Setup (10 minutes)

1. **Install STServo SDK**
   ```bash
   git clone https://github.com/FEETECH-RC/STServo_SDK_Python.git
   cd STServo_SDK_Python
   cp -r STservo_sdk /path/to/your/project/
   ```

2. **Install Python dependencies**
   ```bash
   pip install pyserial
   ```

3. **Configure connection**
   ```python
   DEVICENAME = 'COM7'  # Windows
   # DEVICENAME = '/dev/ttyUSB0'  # Linux
   STS_ID = 1  # Servo ID (use 6 if connected as gripper on SO-ARM101)
   ```

---

## Step 5: First Test (5 minutes)

1. **Connect hardware**
   - Servo → Bus Servo Adapter
   - Bus Adapter → Computer (USB)
   - Power supply (6-12V, min 3A)

2. **Run basic test**
   ```bash
   cd software/python
   python gripper_control.py
   ```

3. **Try basic commands**
   - Enter `45` to open gripper
   - Enter `-45` to close gripper
   - Enter `0` to center
   - Press Enter to exit

---

## Troubleshooting

### Connection Issues
- ✅ Check COM port in Device Manager (Windows) or `ls /dev/ttyUSB*` (Linux)
- ✅ Verify servo power LED is on
- ✅ Try different baud rates (default: 1000000)
- ✅ Check cable connections

### Movement Issues
- ✅ Verify gear engagement with rack
- ✅ Check for mechanical binding
- ✅ Ensure bearings move freely on rods
- ✅ Monitor servo temperature (max 60°C)

### Software Issues
- ✅ Install STServo SDK correctly
- ✅ Check Python version (3.6+)
- ✅ Verify serial port permissions: `sudo chmod 666 /dev/ttyUSB0` (Linux)

---

## Next Steps

🎉 **Congratulations!** Your gripper is working!

Now you can:
- Mount on SO-ARM100/101 robot arm
- Integrate with your control software
- Add a camera to the camera holder
- Create custom applications

## Need Help?

- 📖 Read the [Specifications](specifications.md)
- 📖 Check the [Assembly Guide](assembly-guide.md)
- 📄 [Parallel Gripper Product Spec (PDF)](Parallel%20gripper%20by%20Robo9.pdf)
- 📄 [SO-ARM101 Product Spec (PDF)](SO-ARM101%20by%20Robo9.pdf)
- 🐛 Report issues on GitHub

---

**Welcome to the parallel gripper community!** 🤖

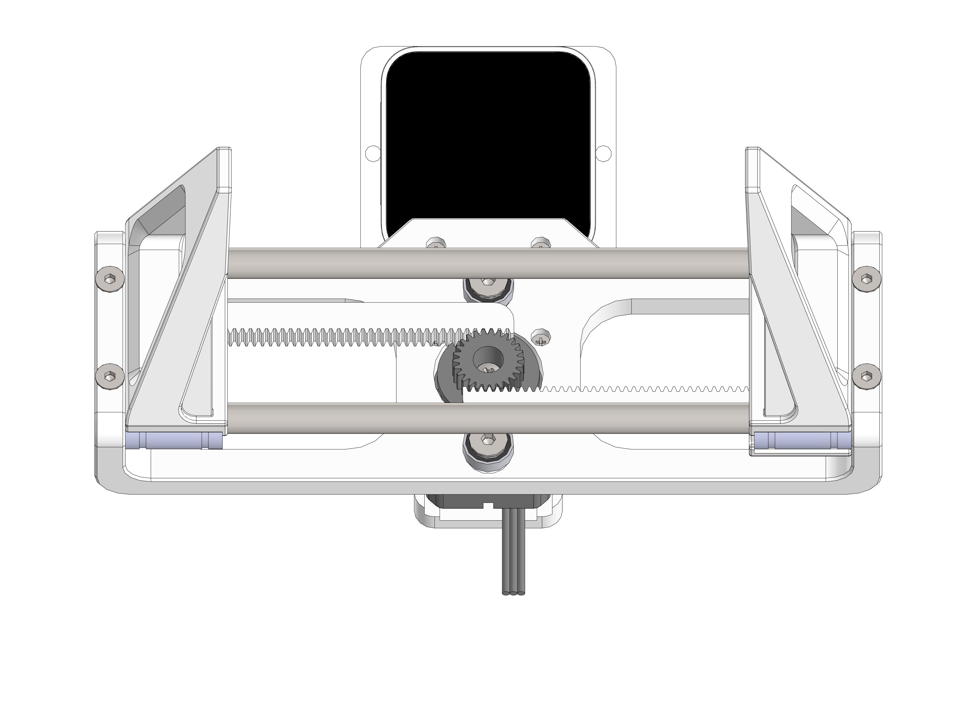
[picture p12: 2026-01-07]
assets/images/specification/06-camera-realsense-d405.jpg

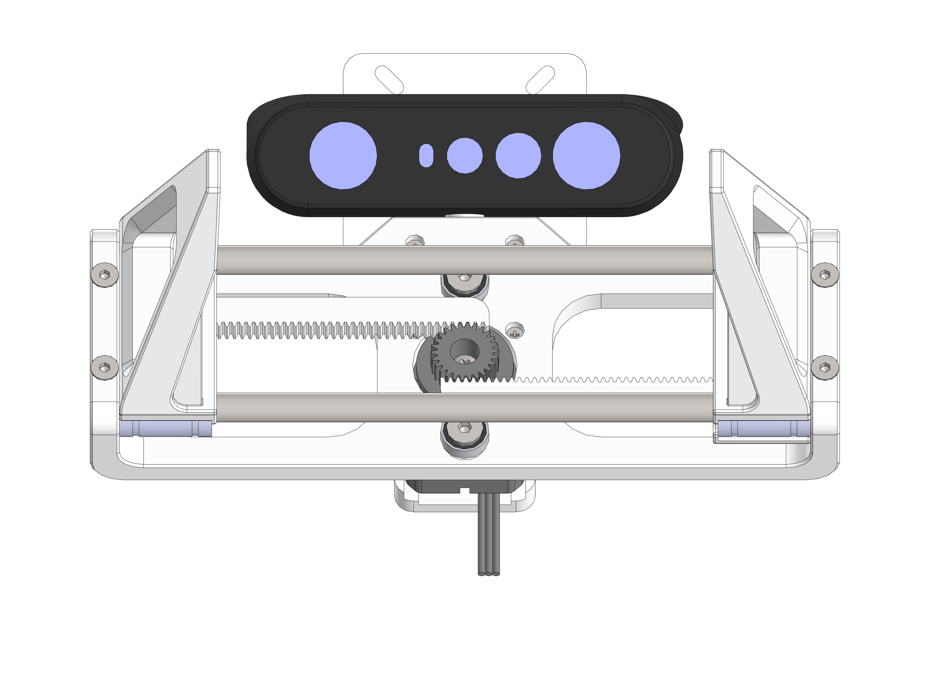
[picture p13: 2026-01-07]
assets/images/specification/05-camera-orbbec-gemini2.jpg

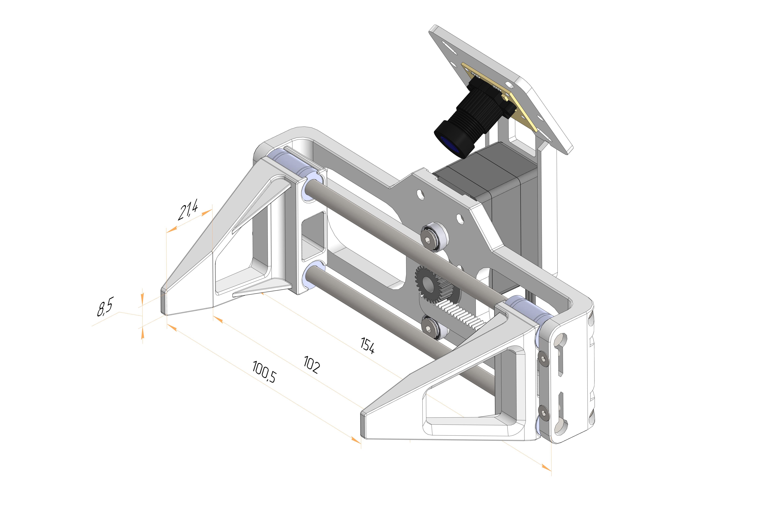
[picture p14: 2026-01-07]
assets/images/specification/02-open-gripper-dimensions.jpg

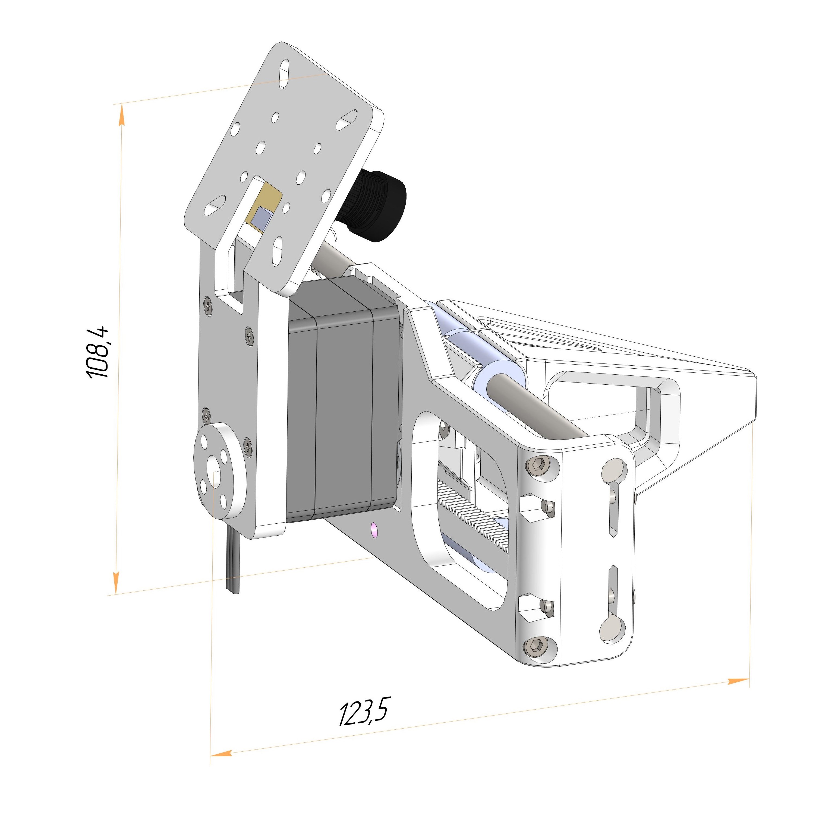
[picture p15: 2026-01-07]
assets/images/specification/01-closed-gripper-dimensions.jpg

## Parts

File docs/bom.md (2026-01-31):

# Bill of Materials (BOM)

## Electronic Components

| Article | Description | Qty | Price | Link |
|---|---|:---:|---|---|
| ST-3215-C018 | Feetech Servo Motor | 1 | ~$29.00 | [Feetech](https://www.feetechrc.com/525603.html) |
| | Bus Servo Adapter Board | 1 | ~$10.99 | [Waveshare](https://www.waveshare.com/bus-servo-adapter-a.htm) |

## Bearings

| Article | Description | Qty | Price | Link |
|---|---|:---:|---|---|
| MR106ZZ | Bearing 6x10x3 mm | 2 | ~$5.49 (10pcs) | [Amazon](https://www.amazon.com/ACROPIX-Bearings-Shielded-Pre-Lubricated-Deep-6x10x3mm/dp/B0C4PGLSCY) |
| LM6UU | Linear Bearing 6x12x19 mm | 4 | ~$8.99 (10pcs) | [Amazon](https://www.amazon.com/Skweawert-LM6UU-Linear-Bearings-Printer/dp/B0D5BGWCYB) |

## Rods

| Article | Description | Qty | Price | Link |
|---|---|:---:|---|---|
| | Round Rod D6x125 mm | 2 | ~$5.56 (2pcs) | [eBay](https://www.ebay.com/itm/374924746654) |

## 3D-Printed Parts

| Part Number | Description | Qty | Est. Price |
|---|---|:---:|---|
| RB9.01.060.015 | Main frame 128mm (follower) | 1 | ~$8.00 |
| RB9.01.060.021 | Clamp | 2 | ~$3.00 |
| RB9.01.060.030 | Gear rack (short) | 2 | ~$2.00 |
| RB9.01.060.041 | Gear for gripper | 1 | ~$2.00 |
| RB9.01.060.073 | Camera holder | 1 | ~$2.00 |

*3D printing estimates based on ~$0.05/g PLA filament + electricity costs*

## Fasteners

| Article | Description | Qty | Price | Link |
|---|---|:---:|---|---|
| | Screw DIN 7991 M3x8 | 8 | ~$6.99 (100pcs) | [Amazon](https://www.amazon.com/Countersunk-Socket-Screws-100-piece-Stainless/dp/B01HBN0X58) |
| | Screw DIN 7991 M3x20 | 4 | ~$6.99 (100pcs) | [Amazon](https://www.amazon.com/Countersunk-Socket-Screws-100-piece-Stainless/dp/B01HBN0X64) |
| | Screw DIN 912 M3x50 | 4 | ~$9.68 (100pcs) | [Amazon](https://www.amazon.com/iExcell-Stainless-Socket-Screws-Threaded/dp/B07C9F2347) |
| | Nut DIN 934 M3 | 4 | ~$6.49 (100pcs) | [Amazon](https://www.amazon.com/Sutemribor-Female-Threaded-Stainless-Steel/dp/B07MLLQ3LH) |
| | Set Screw DIN 913 M3x4 | 4 | ~$6.99 (100pcs) | [Amazon](https://www.amazon.com/Socket-M3-0-5-Metric-14-9-45H-Quantity/dp/B07CPNB1WP) |

---

## Cost Summary

### Follower Gripper

| Category | Items | Est. Cost |
|---|---|---|
| Electronics | Servo ST-3215 + Adapter | ~$40.00 |
| Bearings | MR106ZZ (2) + LM6UU (4) | ~$6.00* |
| Rods | D6x125 (2) | ~$4.00* |
| 3D-Printed Parts | 5 parts | ~$17.00 |
| Fasteners | Various screws & nuts | ~$3.00* |
| **Total** | | **~$70.00** |

### Full Pack Prices (with extras)

| Category | Pack Price |
|---|---|
| Electronics | ~$40.00 |
| Bearings | ~$14.48 |
| Rods | ~$5.56 |
| 3D-Printed Parts | ~$17.00 |
| Fasteners | ~$35.45 |
| **Total** | **~$113.00** |

*\* Pro-rated from bulk pack prices*

---

## Notes

- **Prices** are approximate and based on Amazon/supplier listings as of January 2026
- **Bulk savings**: Fasteners and bearings come in packs, providing extras for future builds
- **3D printing costs** assume home printing with PLA (~200-300g total material)
- **Shipping** not included in estimates
- Consider ordering from single suppliers to reduce shipping costs

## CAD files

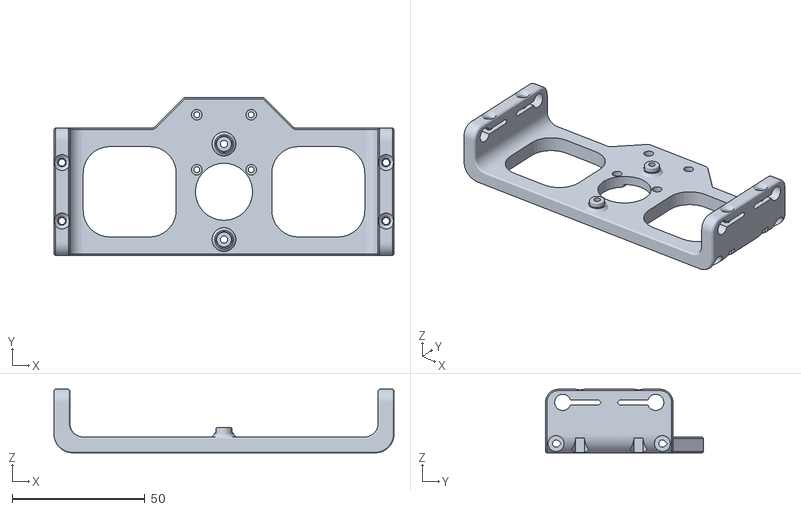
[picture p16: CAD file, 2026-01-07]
models/parts/RB9.01.060.015 Main frame 128mm (follower).STL
128.0 x 59.5 x 24.0

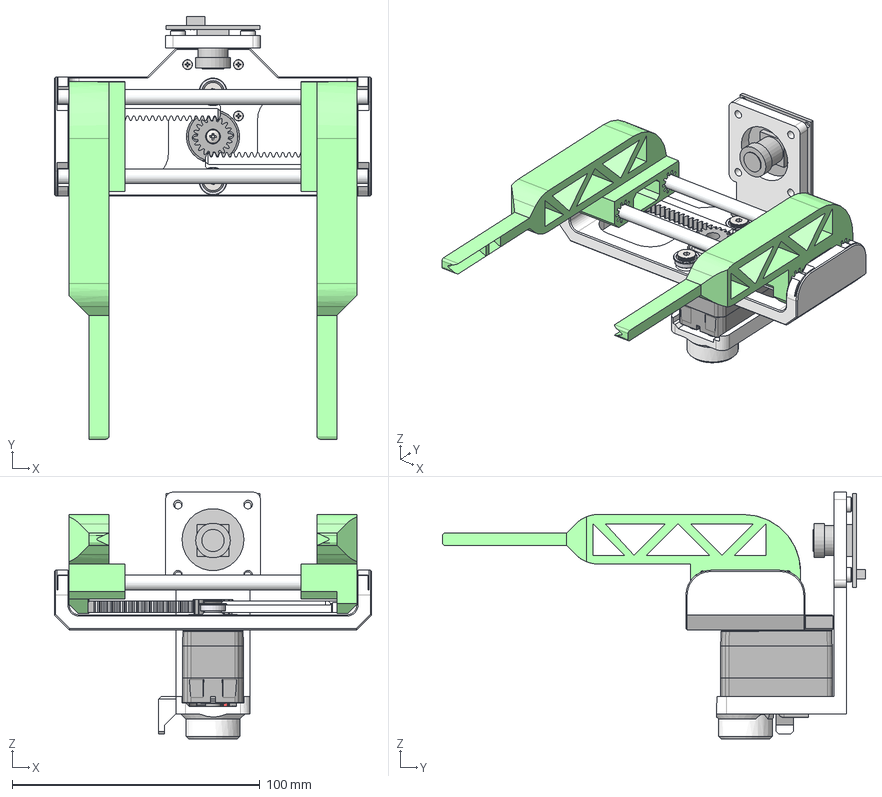
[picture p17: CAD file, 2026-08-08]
community/histology-slide-gripper/cad/the-parallel-microscope-slide-gripper.step
128.0 x 170.6 x 99.5 mm
RB9.01.062.030 Gear rack_m0.8 x 2
RB9.01.062.040 Gear for gripper_ISO - Spur gear 0.8M 18T 20PA 5FW --- S18B10H8L6.0S1
Rod d6_125 x 2
ZK_122^STS3215_Servo
SG-ZIJI_15^STS3215_Servo
XG-ZIJI_16^STS3215_Servo
Main Wheel^STS3215_Servo
pan head cross recess screw_din_DIN EN ISO 7045 - M3 x 4 - Z - 4N
0050375033_¢¯à ¢®
Bearing_MF106 10å6å3 x 2
countersunk flat head cross recess screw_din_DIN EN ISO 7046-1 - M2 x 8 - Z - 8N x 3
socket countersunk head screw_din_DIN 7991 - M4 x 8 --- 8N x 2
RB9.01.062.020 Clamp
RB9.01.062.020 Clamp_1
RB9.01.062.010 Main frame_125 follower
RB9.01.062.070 Camera holder_follower + camera
Arducam_OV9281_B0332_visible_assembly

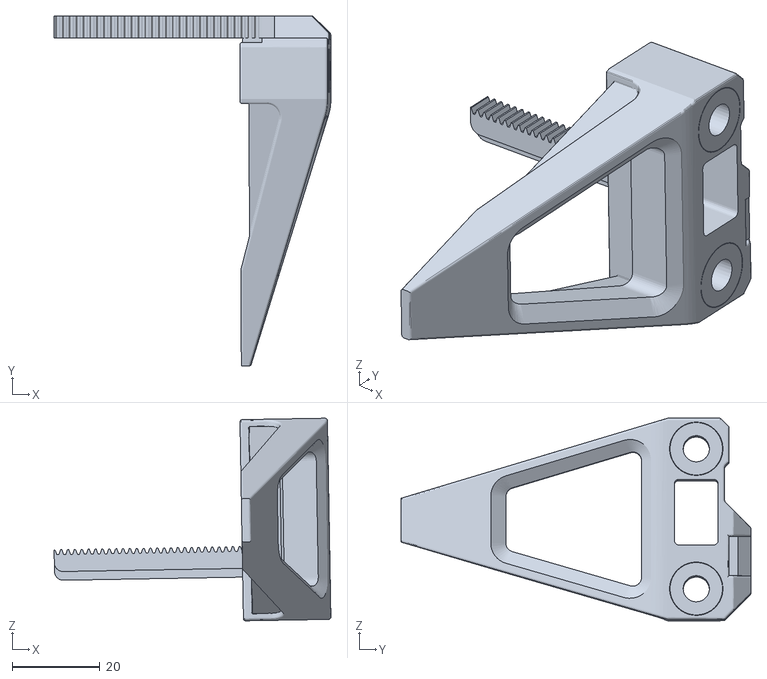
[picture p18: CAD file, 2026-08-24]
community/histology-slide-gripper/mujoco/meshes/arm/clamp_1.stl
63.3 x 80.0 x 46.3

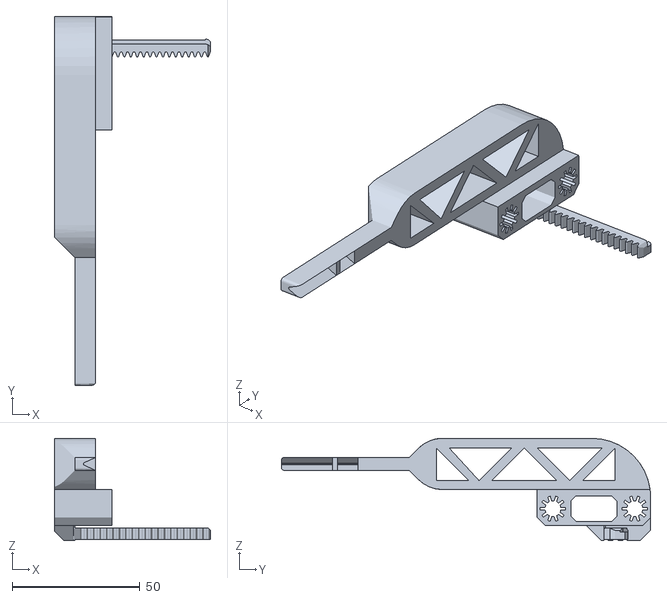
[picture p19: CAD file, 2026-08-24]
community/histology-slide-gripper/mujoco/meshes/jaw_left.stl
61.0 x 144.4 x 40.0

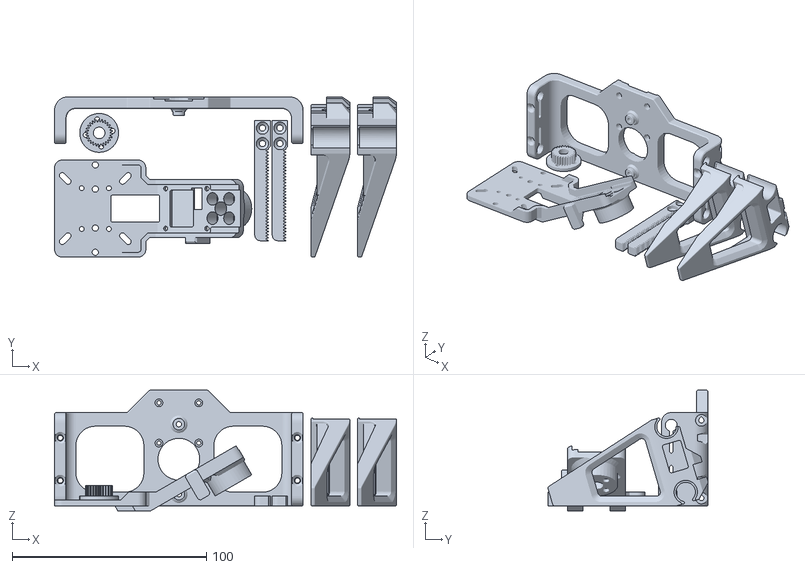
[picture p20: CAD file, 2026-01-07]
models/Follower_Gripper_180x180_BedSize.STL
176.0 x 82.5 x 62.0

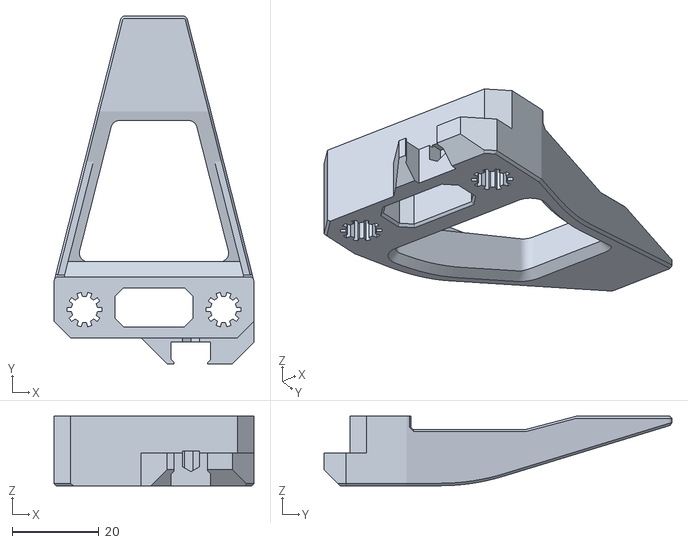
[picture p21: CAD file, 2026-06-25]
models/parts/RB9.01.062.021 (D6.0) Clamp.STL
46.0 x 80.0 x 16.0

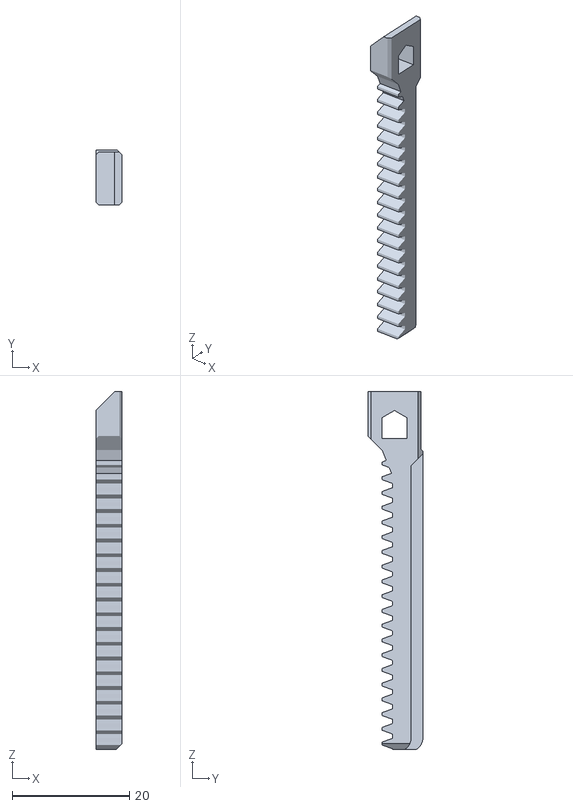
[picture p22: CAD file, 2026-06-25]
models/parts/RB9.01.062.031 Gear rack.STL
4.50 x 9.35 x 61.0

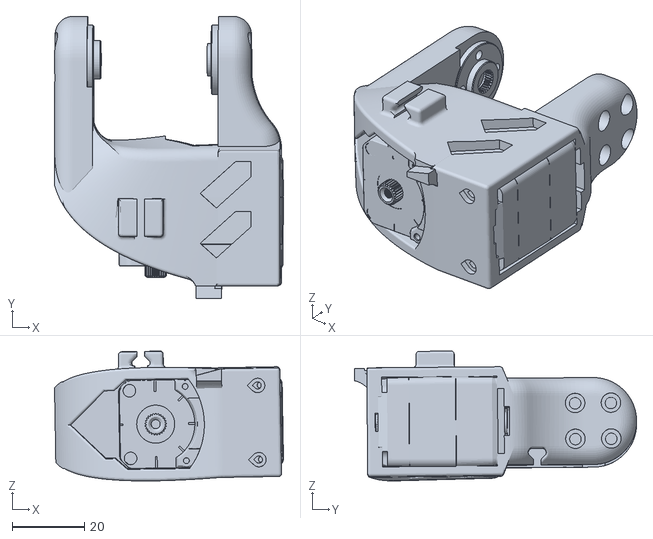
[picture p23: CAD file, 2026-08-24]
community/histology-slide-gripper/mujoco/meshes/arm/link4_1.stl
63.2 x 78.0 x 35.9

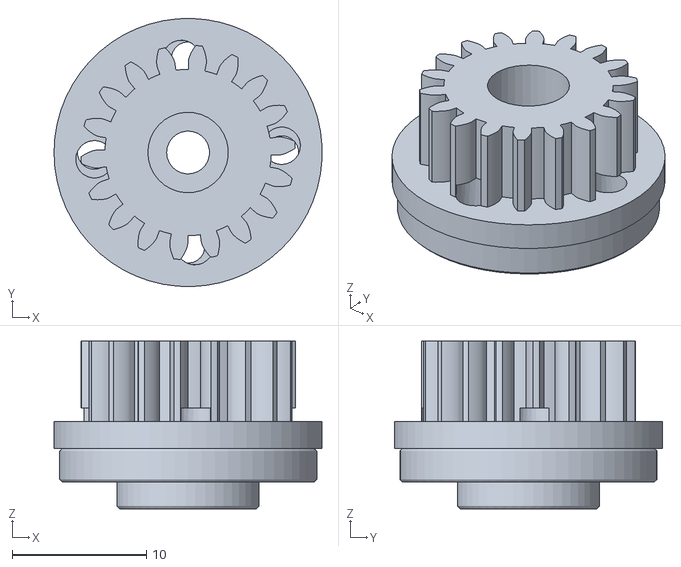
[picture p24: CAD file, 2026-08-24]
community/histology-slide-gripper/mujoco/meshes/pinion.stl
20.0 x 20.0 x 12.5

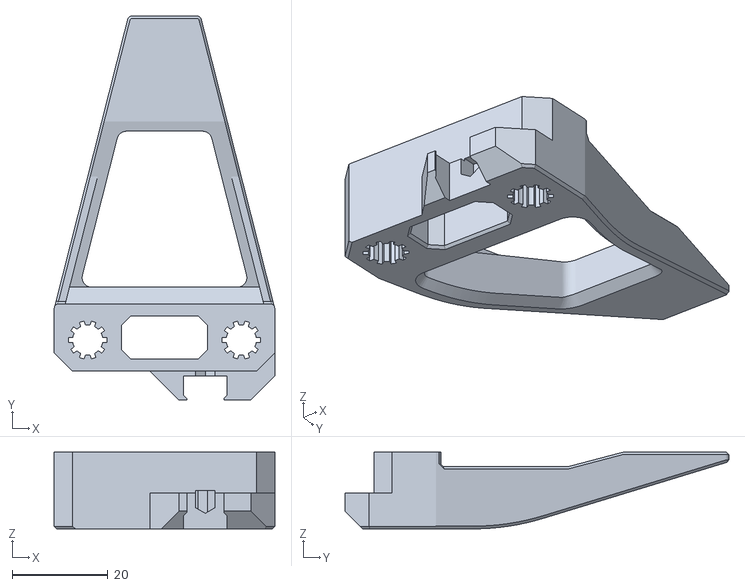
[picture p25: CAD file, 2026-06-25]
models/parts/RB9.01.062.021 (D6.3) Clamp.STL
46.0 x 80.0 x 16.0

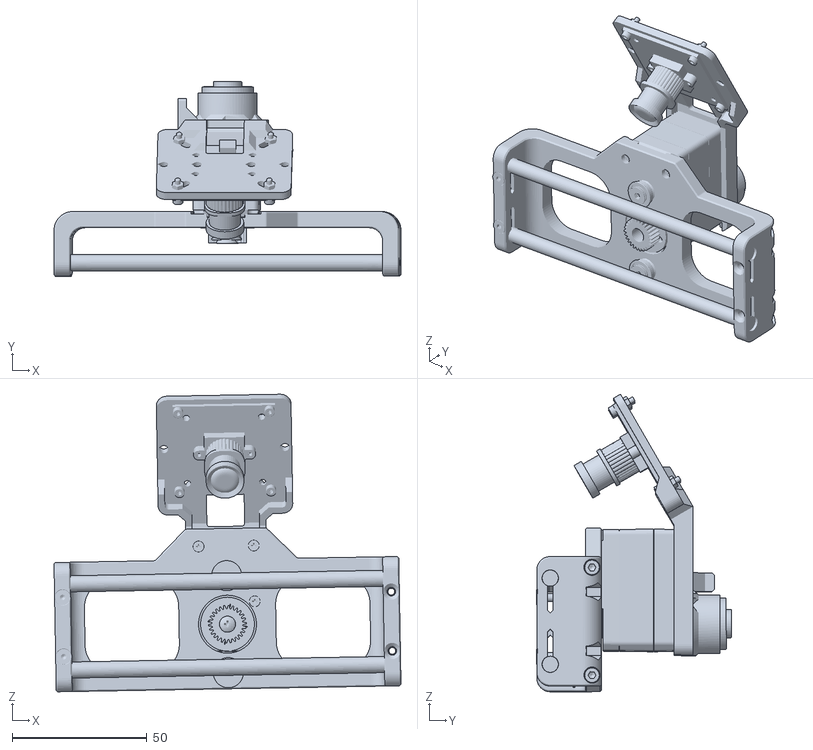
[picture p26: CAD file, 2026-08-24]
community/histology-slide-gripper/mujoco/meshes/arm/link5_1.stl
128.8 x 72.5 x 110.5

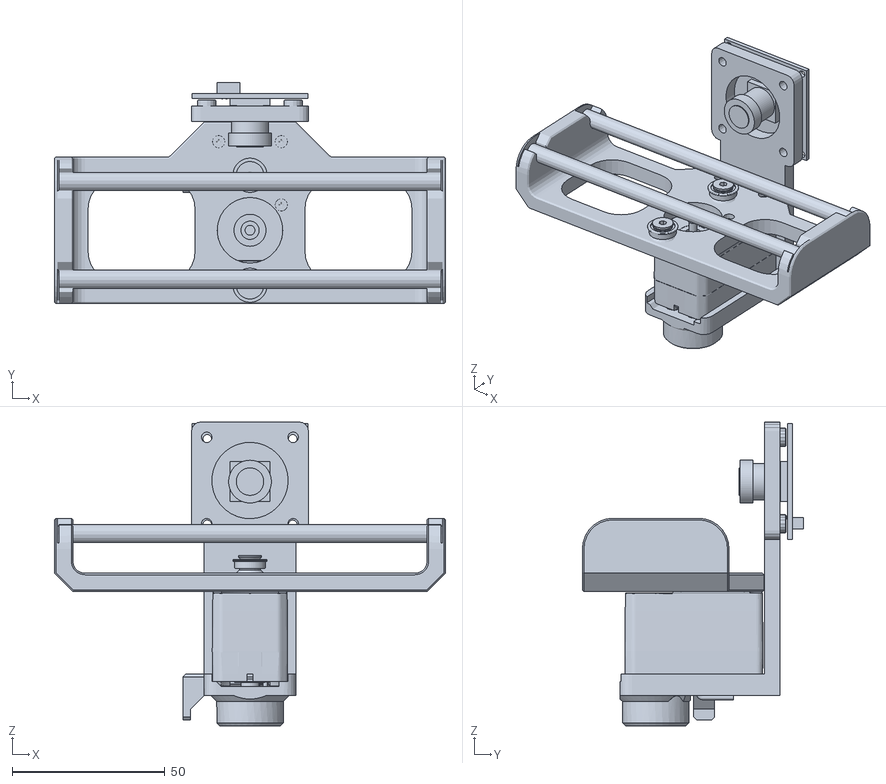
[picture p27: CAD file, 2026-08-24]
community/histology-slide-gripper/mujoco/meshes/base.stl
128.0 x 72.4 x 99.5

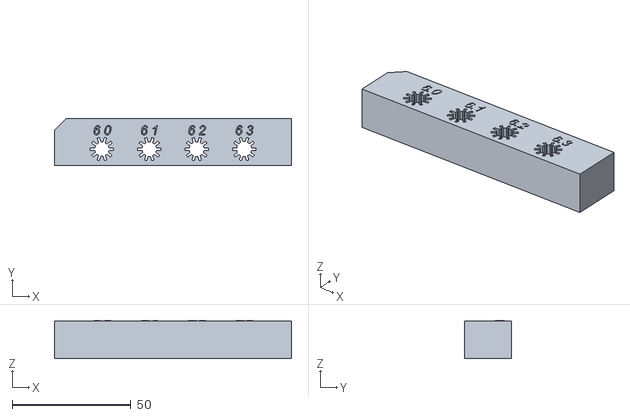
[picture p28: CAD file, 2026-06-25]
models/parts/Gripper test plate star holes 6.0-6.3.STL
100.0 x 20.0 x 16.2

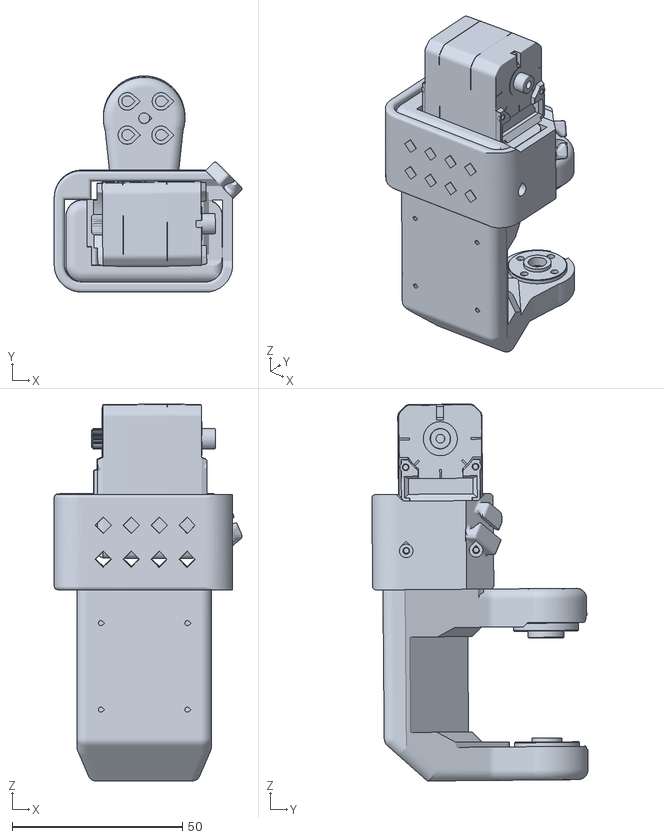
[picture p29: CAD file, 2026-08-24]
community/histology-slide-gripper/mujoco/meshes/arm/link1_1.stl
55.1 x 63.5 x 110.7

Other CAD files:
community/histology-slide-gripper/mujoco/meshes/arm/clamp_2.stl
community/histology-slide-gripper/mujoco/meshes/jaw_right.stl
models/parts/RB9.01.062.021 (D6.2) Clamp.STL
community/histology-slide-gripper/mujoco/meshes/arm/link2_1.stl
community/histology-slide-gripper/cad/the-parallel-microscope-slide-gripper.stl
community/histology-slide-gripper/mujoco/meshes/arm/base_link.stl
community/histology-slide-gripper/mujoco/meshes/arm/link3_1.stl
models/parts/RB9.01.060.021 Clamp.STL
models/parts/RB9.01.060.030 Gear rack (short).STL
models/parts/RB9.01.060.041 Gear for gripper.STL
models/parts/RB9.01.060.073 Camera holder.STL
models/parts/RB9.01.060.110 D405 holder.STL
models/parts/RB9.01.062.021 (D6.1) Clamp.STL
models/parts/RB9.01.062.100 Nail.STL

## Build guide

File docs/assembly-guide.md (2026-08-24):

# Assembly Guide for Follower Gripper SO-ARM101

This guide provides step-by-step instructions for assembling the parallel gripper. Follow these steps carefully to ensure proper operation.

## Required Tools

- Phillips head screwdriver PH1
- Hex keys M2 (H1.5) and M4 (H2.5)

---

## Step 1: Install Gear on Servo

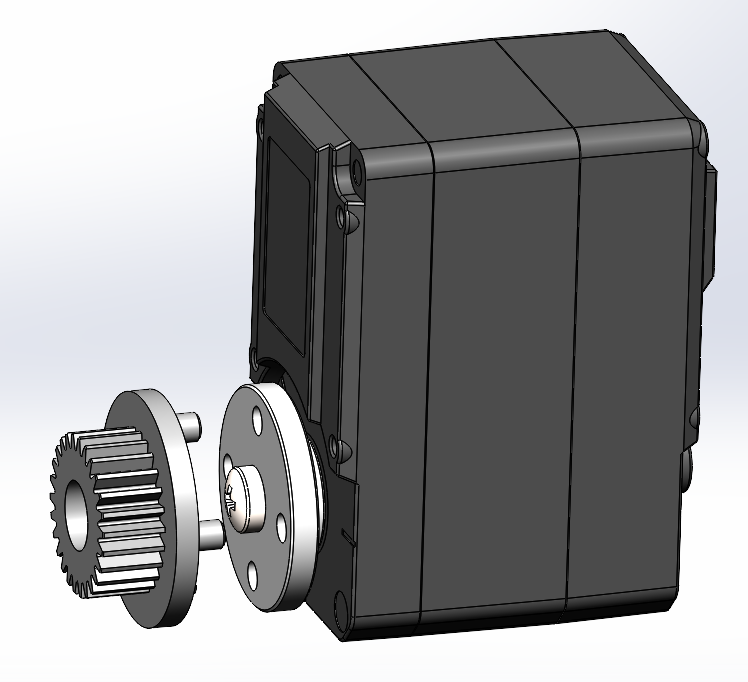
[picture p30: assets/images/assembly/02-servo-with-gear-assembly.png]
Servo with gear assembly


**Components needed:**
- 1x Feetech STS3215 Servo
- 1x Gear  (RB9.01.062.040)
- 1x Servo disk (from servo kit)
- 1x Servo mounting screw M3x6 (from servo kit)
- 4x Set Screw DIN 913 M3x4

**Instructions:**
1. Place Gear for Gripper on Servo disk and tighten 4x Set Screws M3x4 in the direction from Servo disk to Gear. Make sure that no gap appears between Disk and Gear when tightening the screws.
2. Mount the gear assembly onto the servo output shaft.
3. Secure with the screw M3x6 provided in the servo kit.

---

## Step 2: Servo Positioning and Torque Limit

Servo positioning

**Components needed:**
- 1x Serial Bus Servo Board and Cables

**Instructions for Windows users:**
1. Connect Servo to Serial Bus Servo Board, connect Board to PC by USB.
2. Configure the servo with Feetech's **FD** (SCServo Debug) tool. It is closed-source
   Windows software from Feetech and is **not** redistributed in this repository:
   - Official download: <https://www.feetechrc.com/software.html> — look for the FD /
     SCServo Debug archive. Some downloads there are password-protected; request the
     password from Feetech.
   - Open-source cross-platform alternative:
     <https://github.com/Kotakku/FT_SCServo_Debug_Qt>

   The steps below describe the FD interface; the alternative exposes the same
   parameters under similar names.
3. Choose your COM port, select BaudRate 1 000 000, push buttons "Open" and after "Search".
4. Below from the list select your servo.
5. Check the box to enable torque on servo.
6. Move the slider to the left.

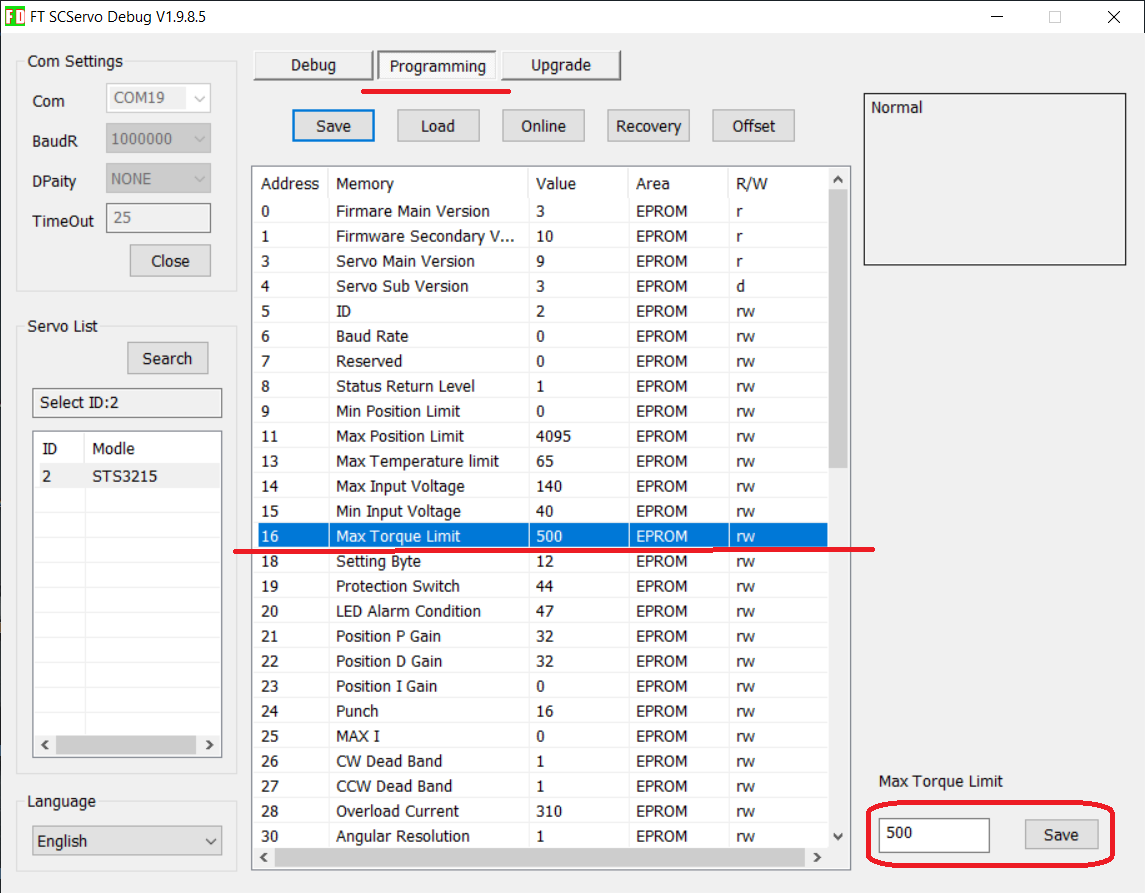
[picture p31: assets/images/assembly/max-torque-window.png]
Max torque limit


7. Switch the window to a tab "Programming".
8. Choose parameter "Max Torque Limit", set it to 500 ans press "Save".

---

## Step 3: Clamps

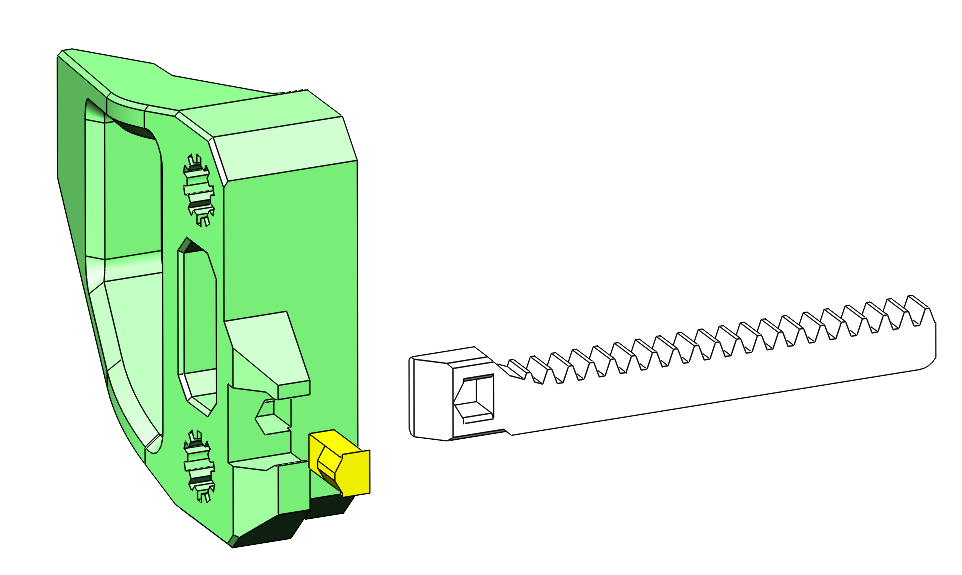
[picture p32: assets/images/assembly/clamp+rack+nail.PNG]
Clamps


**Components needed:**
- 2x Clamps (RB9.01.062.021)
- 2x Gear racks (RB9.01.062.031)
- 2x Nails (RB9.01.062.100)

**Instructions:**
1. Insert gear racks in clamps from side direction.
2. Then insert nails from back direction.

---

## Step 4: Rods

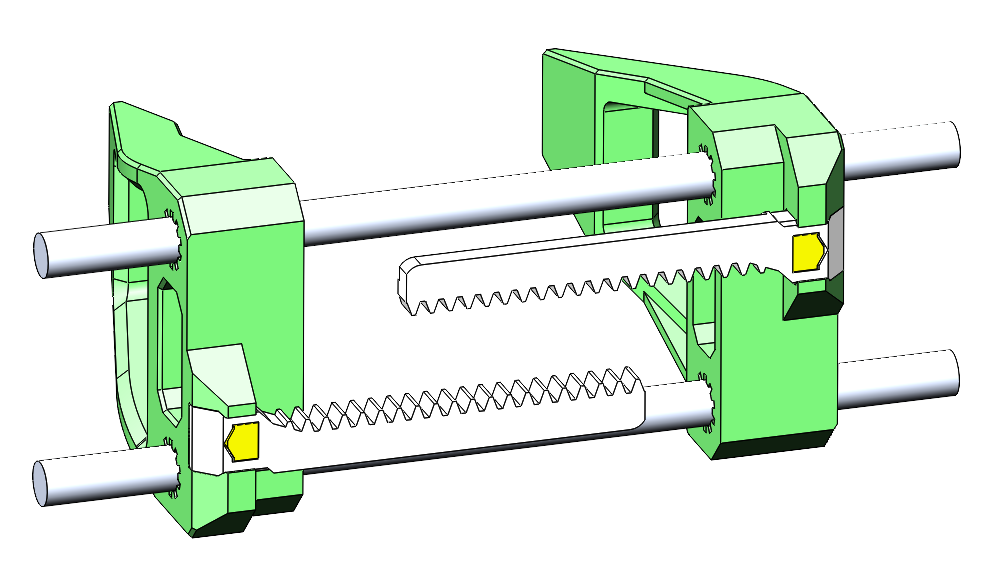
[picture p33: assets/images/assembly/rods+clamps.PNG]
Rods


**Components needed:**
- 2x Rods D6x125mm

**Instructions:**
1. Insert the rods into both clamps. If you ordered rods/tubes longer than 125 mm you need to cut them to this length.

---

## Step 5: Install Bearings on Main Frame

Bearings installed on main frame

**Components needed:**
- 2x MF106ZZ Bearings (10x6x3 mm)
- 2x M4x8 DIN 7991 screws

**Instructions:**
1. Insert the 2x MF106ZZ bearings into their designated positions on the main frame. Bearing flange should face up.
2. Secure each bearing with screw M4x8.

---

## Step 6: Connection of rods and frame

Connection of rods and main frame

**Instructions:**
1. Snap the rods into the frame.
2. Spread the clamps to the extreme positions on the left and right.

---

## Step 7: Mount Servo on Main Frame

Servo mounted on main frame

**Components needed:**
- 3x Self-tapping screws (from servo kit)

**Instructions:**
1. Position the servo on the main frame and align mounting holes.
2. Secure the servo using 3x self-tapping screws from the servo kit.

---

## Step 8: Gripper Holder Attachment

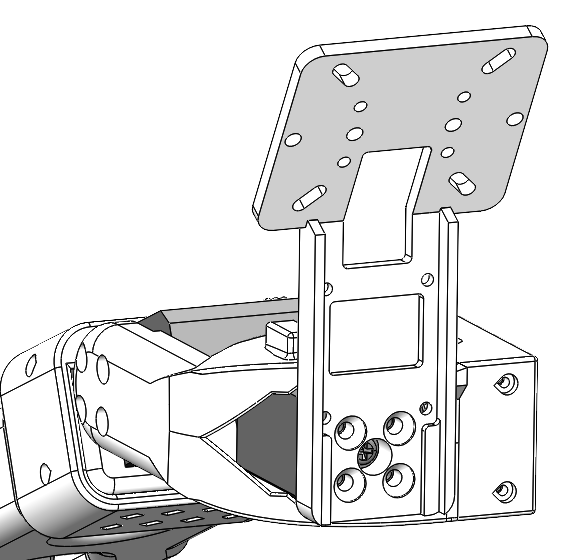
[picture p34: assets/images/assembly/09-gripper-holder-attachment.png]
Gripper holder attachment


**Components needed:**
- 1x Camera holder (RB9.01.060.074) or Holder (RB9.01.060.080)
- 1x SO-ARM101
- 4x M3x6 Screws (from servo kit)
- 4x Self-tapping screws (from servo kit)

**Instructions:**
1. If you plan to use Gripper with camera then attach Camera holder, if you plan to use Gripper without camera then attach Holder to the Wrist Joint horn of SO-ARM101 and fix with 4x M3x6 screws
2. Attach the Parallel Gripper to the Camera holder or Holder and fix with 4x self-tapping screws
3. Connect cable from the Parallel Gripper to servo №5 of SO-ARM101

---

## Step 9: Camera Attachment (optional)

Camera attachment

**Components needed:**
- 1x UVC Camera with mount holes at 28x28 mm
- 1x Camera Spacer (RB9.01.060.090)
- 4x M2x8 Screws
- 4x M2 Nuts

**Instructions:**
1. Put 4x nuts M2 from the back side of Camera Holder.
2. Put Camera Spacer and Camera from the front side and fix with 4x screws M2x8.

---
## Assembly Complete!

Assembled SO-ARM101 with Follower Gripper

Congratulations! Your SO-ARM101 is now assembled and ready for use.

### Next Steps
- Test gripper operation before use

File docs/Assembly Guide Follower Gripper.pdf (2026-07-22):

Assembly Guide for Follower Gripper SO-ARM101

This guide provides step-by-step instructions for assembling the parallel gripper. Follow these steps carefully to ensure proper operation.
Required Tools:
- Phillips head screwdriver
- Hex keys M3 and M4
Step 1: Install Linear Bearings in Clamps

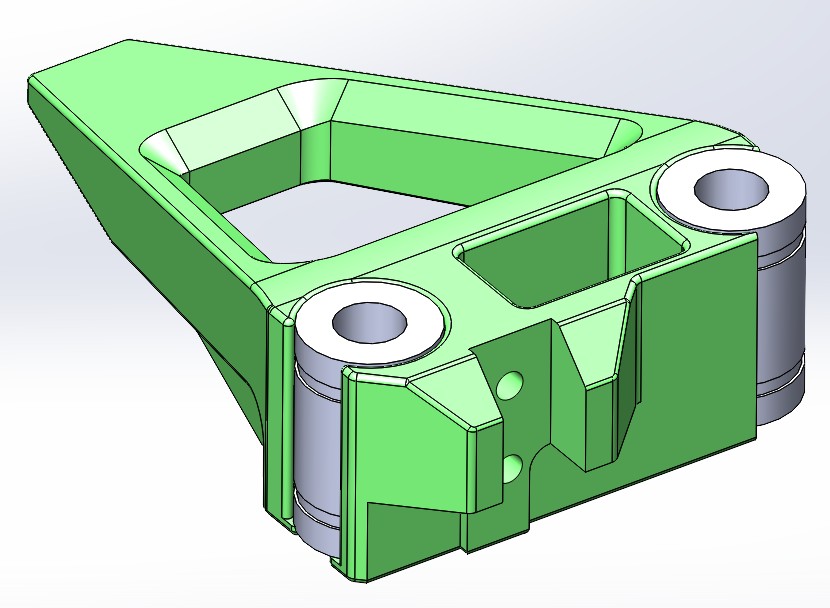
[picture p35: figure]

Components needed:
- 2x Clamps (RB9.01.060.021)
- 4x LM6UU Linear Bearings (12x6x19 mm)
1. Take the first clamp part
2. Carefully press 2x LM6UU bearings into the designated bearing seats, if bearings fit in too easily, wrap some tape around them
3. Ensure bearings are fully seated
4. Repeat for the second clamp
Step 2: Install Gear on Servo Components needed:
- 1x Feetech STS3215 Servo
- 1x Gear for Gripper (RB9.01.060.041)
- 1x Servo disk (from servo kit)
- 1x Servo mounting screw M3x6 (from servo kit)
- 4x Set Screw DIN 913 M3x4

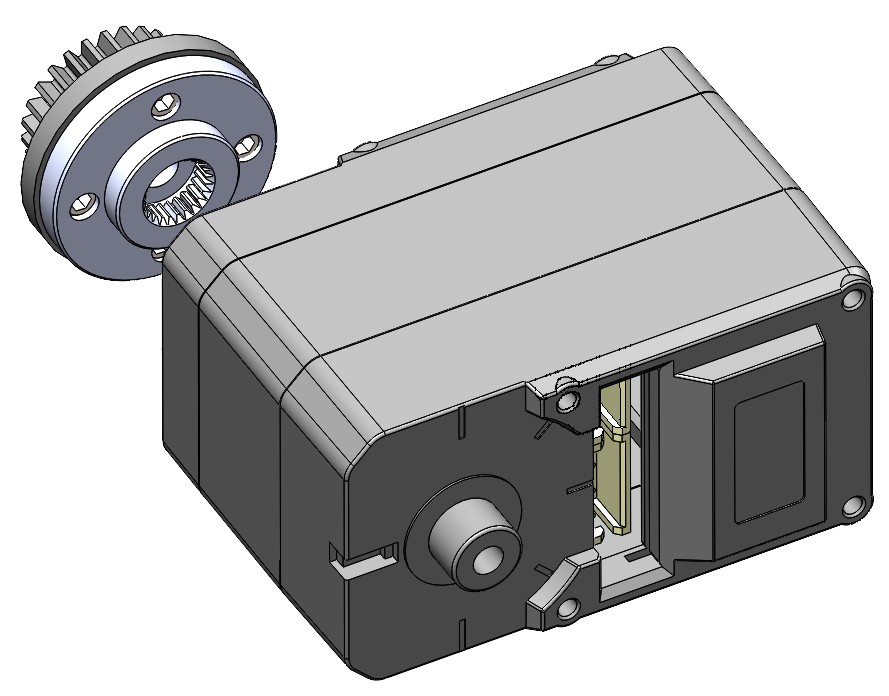
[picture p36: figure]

1. Place Gear for Gripper on Servo disk and fix them together with 4x Set Screws M3x4, pay attention that there is no gap between parts
2. Mount the gear assembly onto the servo output shaft
3. Secure with the screw M3x6 provided in the servo kit
Step 3: Mount Servo on Main Frame

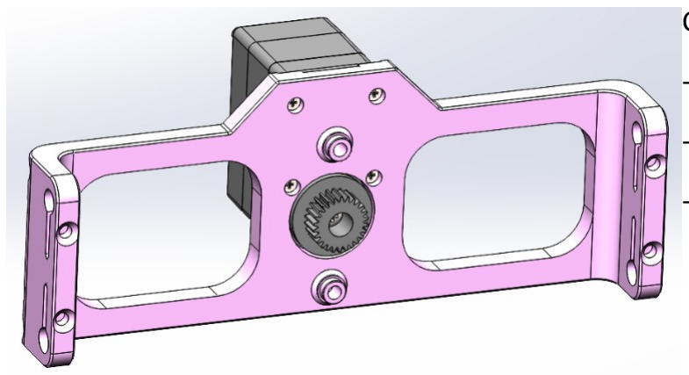
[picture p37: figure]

Components needed:
- 1x Main Frame (RB9.01.060.015)
- 1x Assembled servo with gear
- 4x Self-tapping screws (from servo kit)
1. Position the servo on the main frame and align mounting holes
2. Secure the servo using 4x self-tapping screws from the servo kit
Step 4: Install Bearings on Main Frame

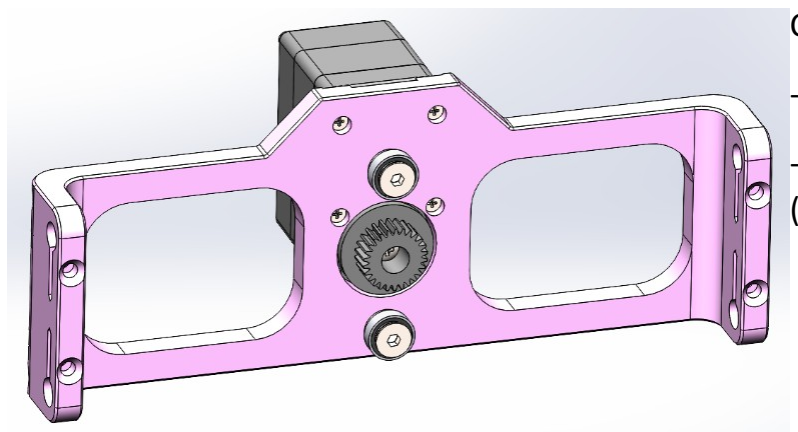
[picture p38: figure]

Components needed:
- 2x MR106ZZ Bearings (10x6x3 mm)
- 2x Self-tapping screws with a large head (from servo kit)
1. Insert the 2x MR106ZZ bearings into their designated positions on the main frame
2. Secure each bearing with self-tapping screw

Step 5: Install Rods and Clamps

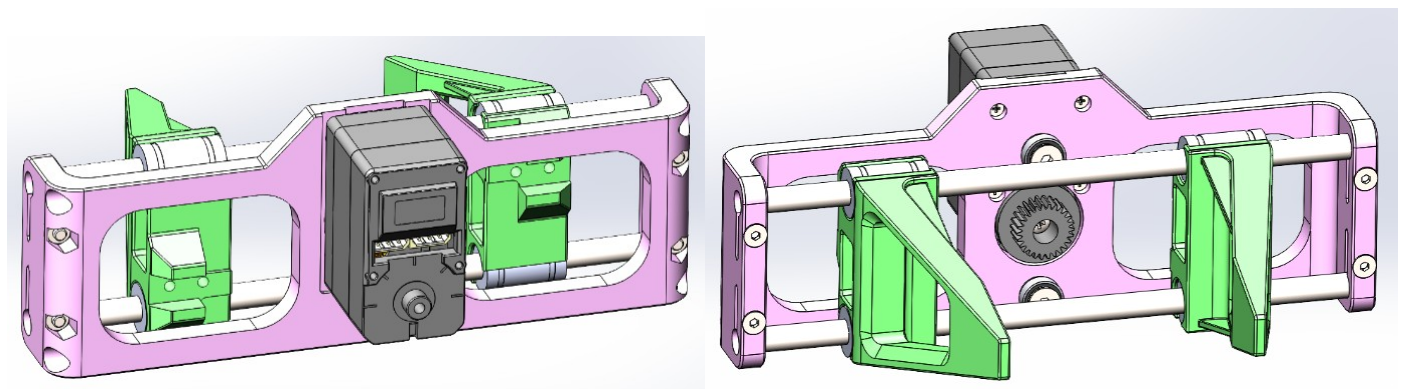
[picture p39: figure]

Components needed:
- 2x Stainless Steel Rods (6mm diameter, 125mm length)
- 2x Assembled clamps (with LM6UU bearings)
- 4x M3x20 DIN 7991 screws
- 4x M3 DIN 934 nuts
1. Insert the 2x steel rods through the one side of main frame
2. Slide the 2x clamps onto the rods
3. Press rods further through the second side of the main frame
4. Secure rods in the main frame using 4x M3x20 screws and 4x M3 nuts
Step 6: Attach Gear Racks

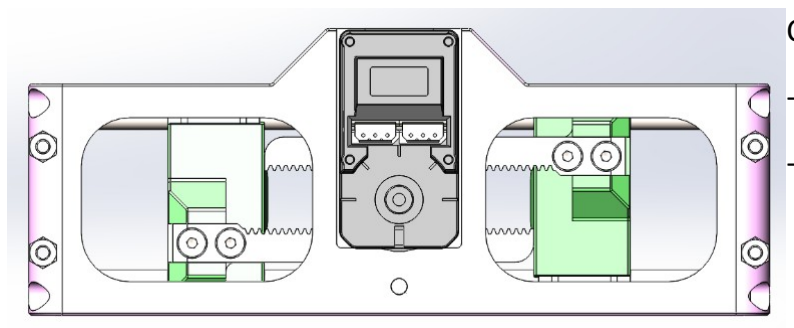
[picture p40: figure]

Components needed:
- 2x Gear Racks (RB9.01.060.030)
- 4x M3x10 DIN 7991 screws
1. Position the gear racks on the back side of each clamp
2. Important: Ensure clamps are symmetrically positioned from the main frame center
3. The gear racks should engage properly with the drive gear
4. Secure each gear rack with 2x M3x10 screws

Step 7: Insert Servo Cable

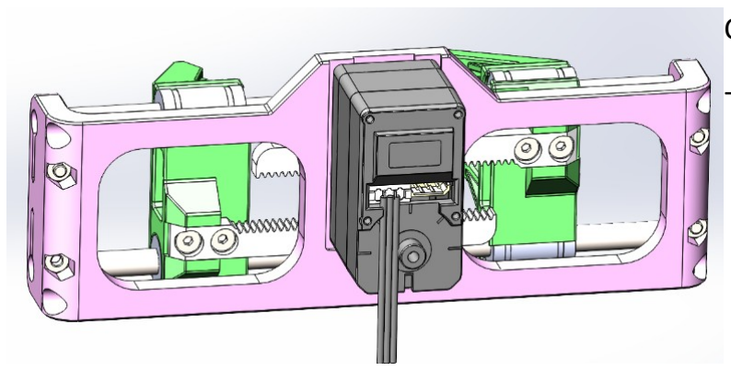
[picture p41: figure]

Components needed:
- Servo cable (from servo kit)
1. Insert cable so it will go straight down
Step 8: Insert Screws for Rigidity

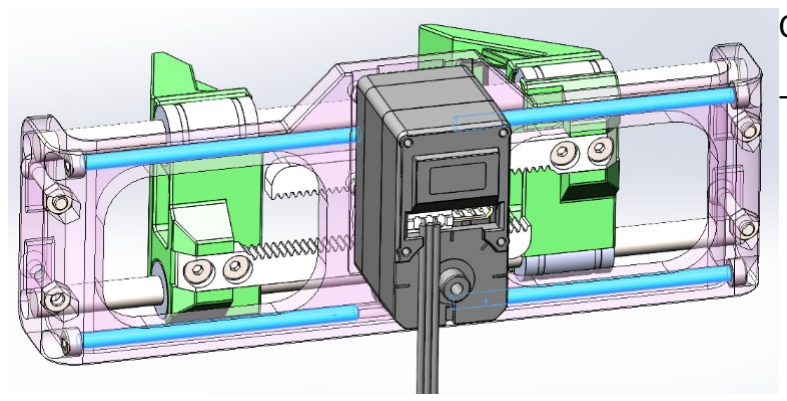
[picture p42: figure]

Components needed:
- 4x M3x50 DIN 912 screws
1. From each side of the Main Frame screw 2x screws M3x50

Congratulations! Gripper is assembled.

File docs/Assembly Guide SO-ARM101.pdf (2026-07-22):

Assembly Guide SO-ARM101

This guide provides step-by-step instructions for assembling the SO-ARM101. Follow these steps carefully to ensure proper operation.
Required Tools:
- Phillips head screwdriver
- Small pliers (for handling cables)
Step 1: Servos preassembly Components needed:
- 5x STS3215
- 5x Servo Cables (from servo kit)
- 5x Motor Horns (from servo kit)
- 4x Passive Horns (from servo kit)
- 5x M3x6 Screws (from servo kit)
- 4x Long self-tapping screws (from servo kit)
Repeat next steps for each servo.
1. Install servo horn, secure with M3x6 screw.
2. Install passive horn, secure with self-tapping screw. Make this step only for 4x servos, one leave with only a servo horn. This servo will be needed for the very last wrist joint.
3. Connect one 3-pin cable.

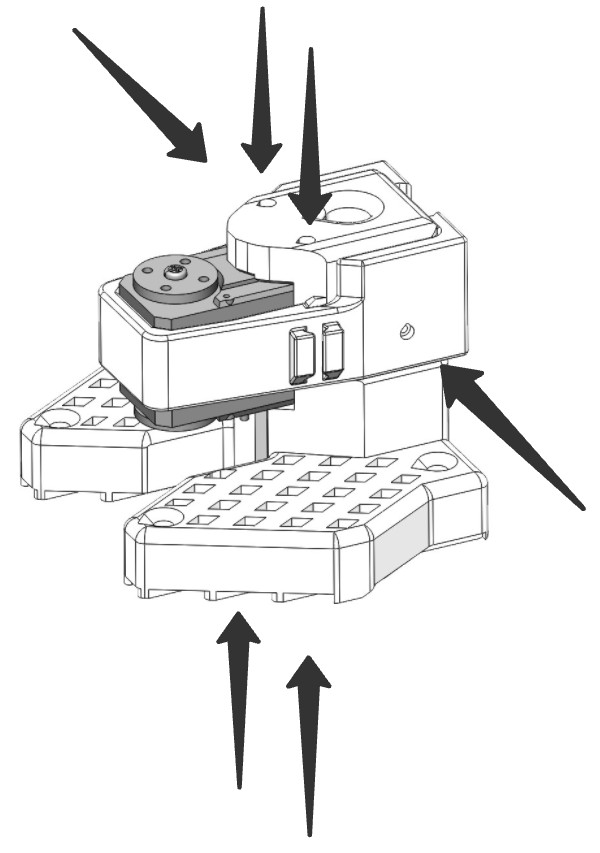
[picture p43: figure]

Step 2: Base assembly
Components needed:
- 1x Base_SO101
- 1x Base_motor_holder_SO101
- 1x STS3215
- 6x Self-tapping screws (from servo kit)

1. Place the first servo into the Base_SO101 (cable looking down).
2. Fasten the servo with 4 self-tapping screws (smallest screws). Two from the top and two from the bottom.
3. Slide over the first servo Base_motor_holder_SO101 and fasten it using two self-tapping screws (one on each side).
Step 3: Waist Joint Assembly
Components needed:
- 1x Rotation_Pitch_SO101
- 1x Motor_holder_SO101_Base
- 1x STS3215
- 8x M3x6 Screws (from servo kit)
- 4x Self-tapping screws (from servo kit)

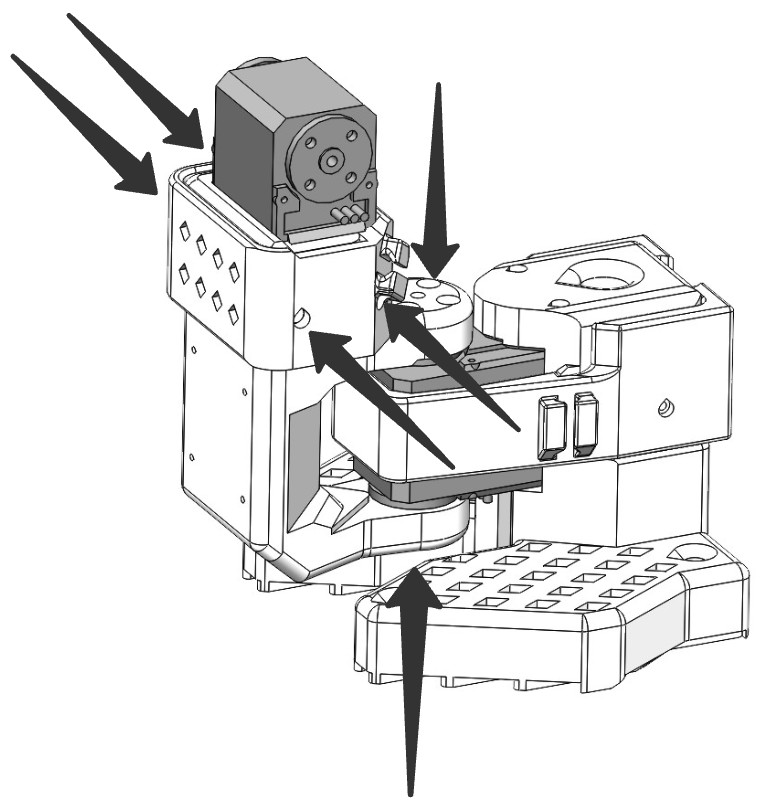
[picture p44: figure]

1. Attach the Rotation_Pitch_SO101 part.
2. Tighten it with 4 M3x6mm screws on top and 4 M3x6mm screws on the bottom.
3. Add the Motor_holder_SO101_Base.
4. Slide the second servo in from the top (pay attention that cable is looking at us).
5. Fasten the second servo with 4 self-tapping screws.

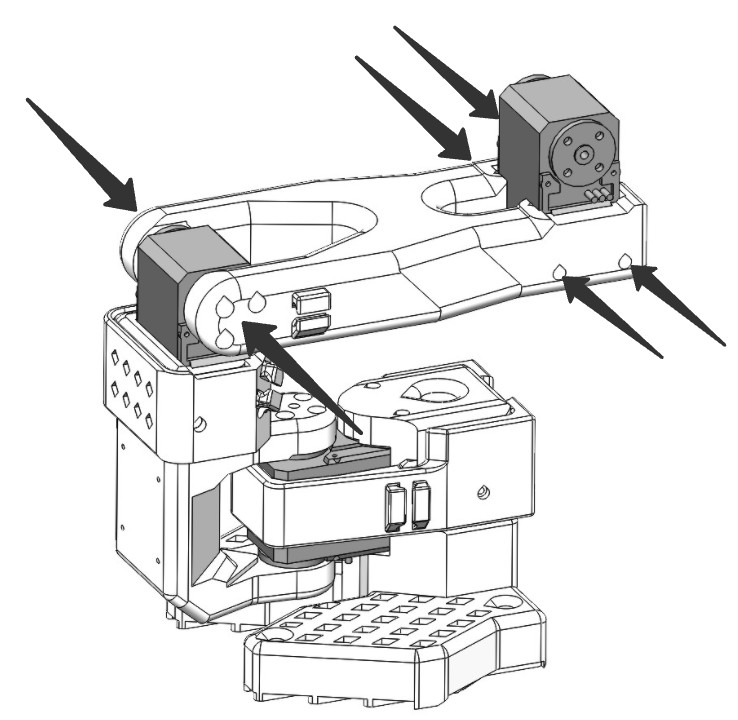
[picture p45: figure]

Step 4: Shoulder Joint Assembly Components needed:
- 1x Upper_arm_SO101
- 1x STS3215
- 8x M3x6 Screws (from servo kit)
- 4x Self-tapping screws (from servo kit)

1. Attach the Upper_arm_SO101 with 4 M3x6mm screws on each side.
2. Insert servo №3 and fasten using 4 self-tapping screws (pay attention that cable is looking at us).
Step 5: Forearm Joint Assembly
Components needed:
- 1x Under_arm_SO101
- 1x Motor_holder_SO101_Wrist
- 1x STS3215
- 8x M3x6 Screws (from servo kit)
- 4x Self-tapping screws (from servo kit)

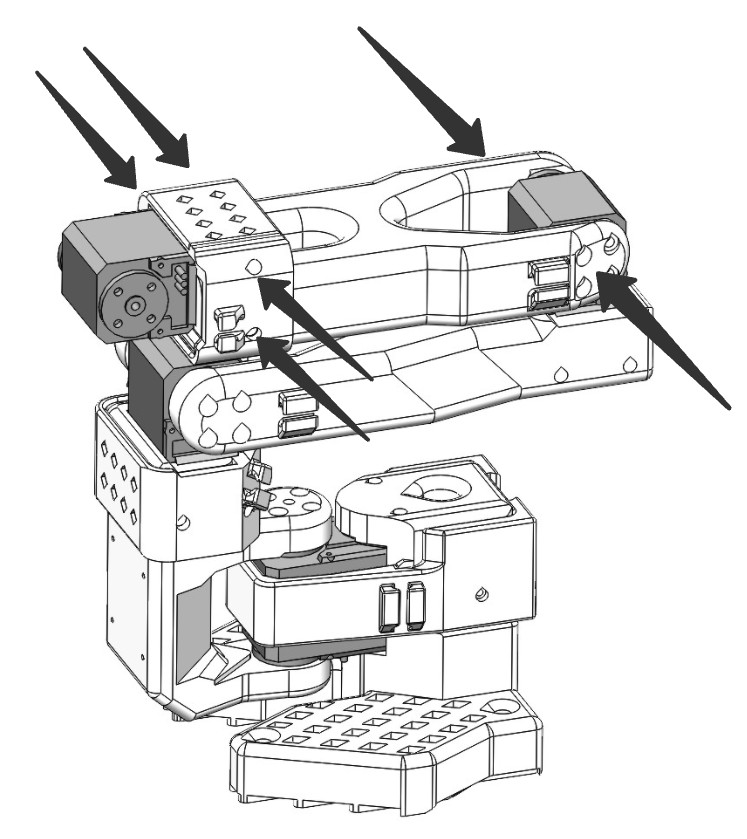
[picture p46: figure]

1. Attach the Under_arm_SO101 with 4 M3x6mm screws on each side.
2. Add the Motor_holder_SO101_Wrist.
3. Insert servo №4 and fasten using 4 self-tapping screws (pay attention that cable is looking at us).
Step 6: Wrist Joint Assembly
Components needed:
- 1x Wrist_Roll_Pitch_SO101
- 1x STS3215
- 8x M3x6 Screws (from servo kit)
- 2x Self-tapping screws (from servo kit)

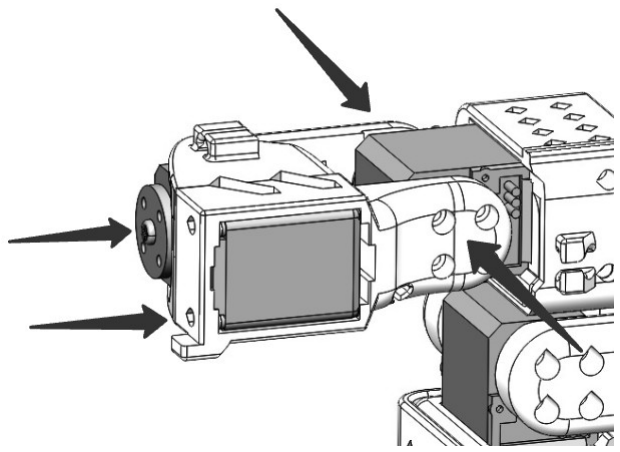
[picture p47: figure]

1. Insert servo №5 into Wrist_Roll_Pitch_SO101 and fix it with 2x Self-tapping screws.
2. Attach this assembly and fix it with 4 M3x6mm screws on each side.
Step 7: Control Board Fixing
Components needed:
- 1x WaveShare_Mounting_Plate_SO101
- 1x WaveShare Bus Servo Adapter
- 4x M2x8 screws

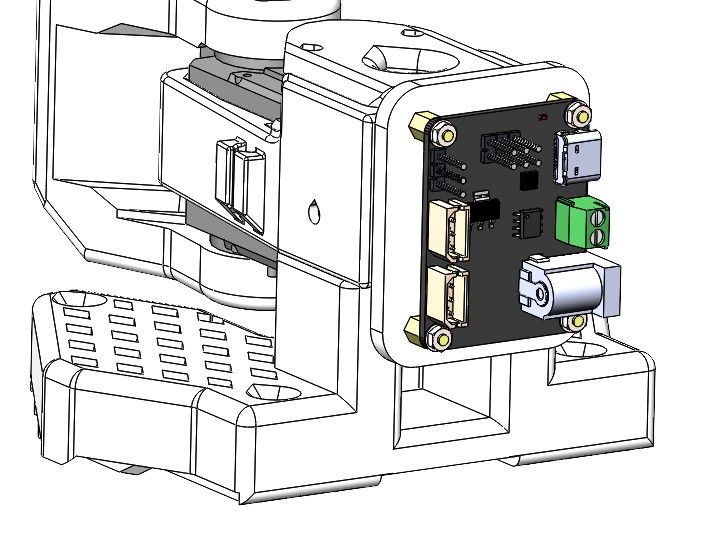
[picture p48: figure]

1. Attach WaveShare Bus Servo Adapter to the WaveShare_Mounting_Plate_SO101 and fix it with 4 M2x8 screws.
2. Slide it down on the Base_SO101 from the assembly step 1.
Step 8: Cables Connecting

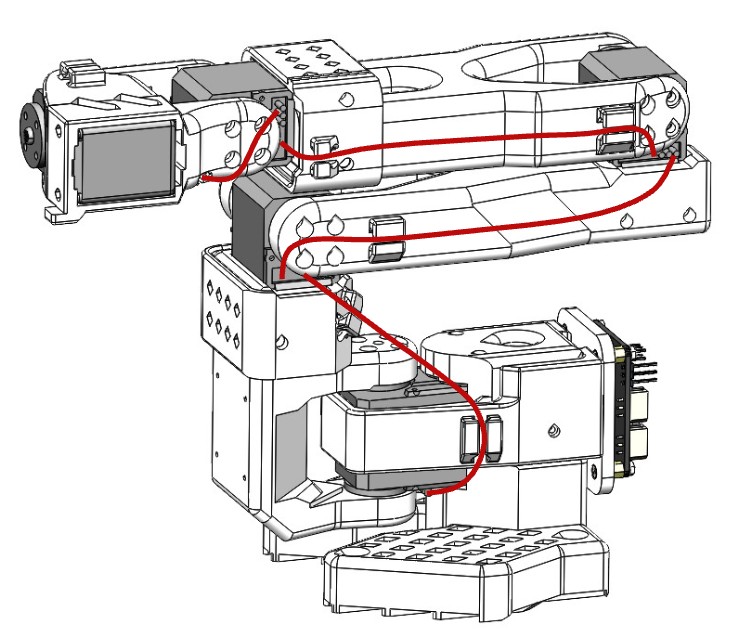
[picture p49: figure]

1. Connect all cables from the servos to each other in a chain.
2. Cable from first servo connect to WaveShare Bus Servo Adapter.

Step 9: Gripper Holder Attachment Components needed:
- 1x Camera holder (RB9.01.060.071) or Servo plate (RB9.01.060.080)
- 1x Parallel Gripper SO-ARM101
- 4x M3x6 Screws (from servo kit)
- 4x Self-tapping screws (from servo kit)

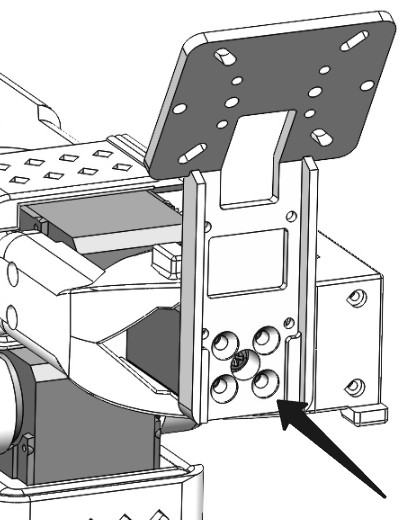
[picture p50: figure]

1. Depending on what type of Gripper you want to connect attach to the Wrist Joint horn Camera holder or Servo plate and fix with 4 M3x6 screws.
2. Attach the Parallel Gripper to the Camera holder or Servo plate and fix with 4 self-tapping screws.
3. Connect cable from the Parallel Gripper to the servo №5 .

Your SO-ARM101 is now assembled.

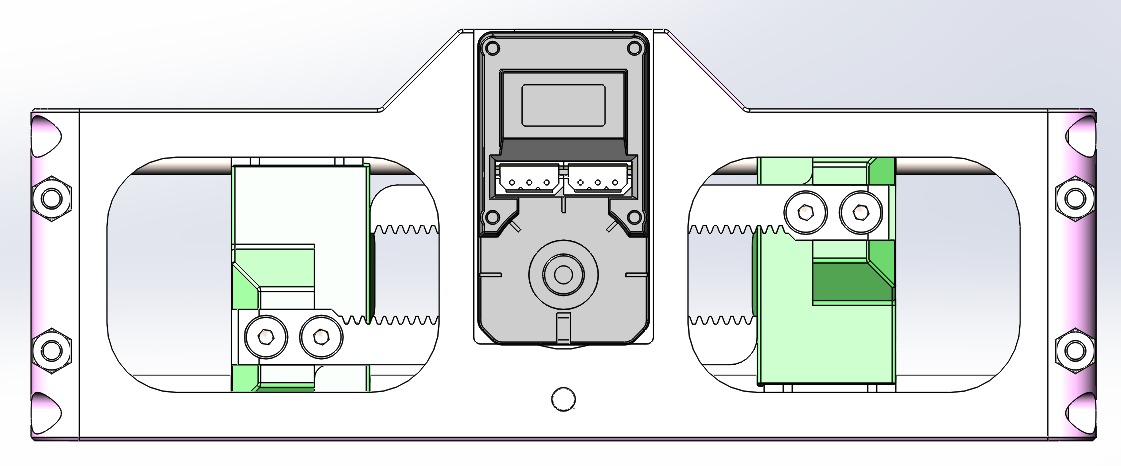
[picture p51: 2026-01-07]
assets/images/assembly/06-gear-racks-top-view.png

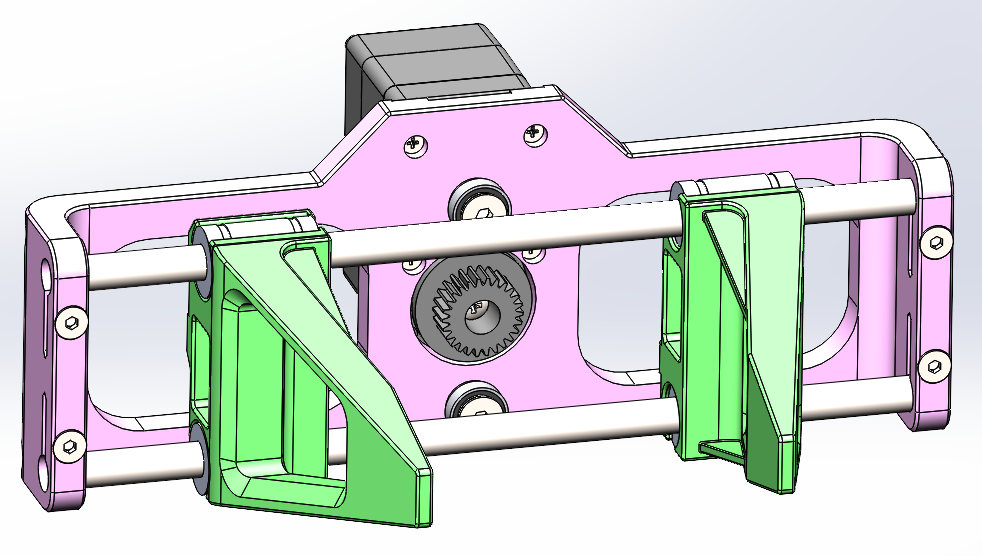
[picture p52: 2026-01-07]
assets/images/assembly/05b-rods-and-clamps-front-view.png

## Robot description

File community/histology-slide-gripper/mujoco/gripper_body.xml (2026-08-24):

<mujocoinclude>
  <!-- Frame convention (inherited from the Fusion assembly):
         origin = drive-pinion axis,  +Z = pinion axis (servo hangs at -Z),
         +-X    = jaw travel,         -Y = direction the jaws point.
       Jaw joints read 0 = fully open (84 mm between the blade faces) and
       0.0355 = fully closed (13 mm), matching the 35.5 mm rack travel. -->
  <body name="slide_gripper_base" pos="0 0 0">
    <geom type="mesh" mesh="sg_base" material="sg_frame" mass="0.20" contype="0" conaffinity="0" group="2"/>
    <geom name="sg_base_col" type="box" pos="0 0.012 -0.0023" size="0.064 0.036 0.0498" mass="0" group="3" rgba="0.5 0.5 0.5 0.25"/>

    <!-- Drive pinion: 18T, 0.8 module, 7.2 mm pitch radius. Kinematically
         redundant (the racks are coupled directly) but kept so the gear
         visibly turns with the jaws. -->
    <body name="sg_pinion" pos="0 0 0">
      <joint name="sg_pinion_joint" type="hinge" axis="0 0 1" limited="false" damping="0.001" armature="1e-4"/>
      <geom type="mesh" mesh="sg_pinion" material="sg_gear" mass="0.008" contype="0" conaffinity="0" group="2"/>
    </body>

    <body name="sg_jaw_right" pos="0 0 0">
      <joint name="sg_jaw_right_joint" type="slide" axis="-1 0 0" range="0 0.0355" damping="2.0" armature="0.001"/>
      <geom type="mesh" mesh="sg_jaw_right" material="sg_jaw" mass="0.035" contype="0" conaffinity="0" group="2"/>
      <geom name="sg_pad_right" type="box" pos="0.046 -0.10719 0.0285" size="0.004 0.015 0.0025" mass="0" group="3" material="sg_pad" friction="1.5 0.02 0.005" solimp="0.98 0.999 0.001" solref="0.004 1"/>
      <geom name="sg_mid_right" type="box" pos="0.050 -0.05856 0.0285" size="0.008 0.0136 0.010" mass="0" group="3" material="sg_pad" friction="1.5 0.02 0.005" solimp="0.98 0.999 0.001" solref="0.004 1"/>
    </body>

    <body name="sg_jaw_left" pos="0 0 0">
      <joint name="sg_jaw_left_joint" type="slide" axis="1 0 0" range="0 0.0355" damping="2.0" armature="0.001"/>
      <geom type="mesh" mesh="sg_jaw_left" material="sg_jaw" mass="0.035" contype="0" conaffinity="0" group="2"/>
      <geom name="sg_pad_left" type="box" pos="-0.046 -0.10719 0.0285" size="0.004 0.015 0.0025" mass="0" group="3" material="sg_pad" friction="1.5 0.02 0.005" solimp="0.98 0.999 0.001" solref="0.004 1"/>
      <geom name="sg_mid_left" type="box" pos="-0.050 -0.05856 0.0285" size="0.008 0.0136 0.010" mass="0" group="3" material="sg_pad" friction="1.5 0.02 0.005" solimp="0.98 0.999 0.001" solref="0.004 1"/>
    </body>

    <!-- Arducam OV9281 optical frame, from the camera holder in the CAD -->
    <site name="sg_camera" pos="0 0.044 0.028" quat="0.70710678 0.70710678 0 0" size="0.004"/>
    <site name="sg_tcp" pos="0 -0.10719 0.0285" size="0.004" rgba="1 0 1 1"/>
  </body>
</mujocoinclude>

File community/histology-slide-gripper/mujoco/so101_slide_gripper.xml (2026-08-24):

<mujoco model="so101_slide_gripper">
  <compiler angle="radian" meshdir="." />
  <option timestep="0.002" integrator="implicitfast" />
  <visual>
    <global offwidth="1600" offheight="1200" />
    <quality shadowsize="4096" />
  </visual>
  <!-- gripper geometry, exported from Fusion -->
  <include file="gripper_assets.xml" />
  <asset>
    <mesh name="base_link" content_type="model/stl" file="meshes/arm/base_link.stl" scale="0.001 0.001 0.001" />
    <mesh name="link1_1" content_type="model/stl" file="meshes/arm/link1_1.stl" scale="0.001 0.001 0.001" />
    <mesh name="link2_1" content_type="model/stl" file="meshes/arm/link2_1.stl" scale="0.001 0.001 0.001" />
    <mesh name="link3_1" content_type="model/stl" file="meshes/arm/link3_1.stl" scale="0.001 0.001 0.001" />
    <mesh name="link4_1" content_type="model/stl" file="meshes/arm/link4_1.stl" scale="0.001 0.001 0.001" />
    <mesh name="link5_1" content_type="model/stl" file="meshes/arm/link5_1.stl" scale="0.001 0.001 0.001" />
    <texture name="grid" type="2d" builtin="checker" rgb1="0.25 0.27 0.30" rgb2="0.32 0.34 0.38" width="512" height="512" />
    <material name="grid" texture="grid" texrepeat="8 8" reflectance="0.1" />
    <texture name="sky" type="skybox" builtin="gradient" rgb1="0.35 0.42 0.52" rgb2="0.05 0.06 0.08" width="256" height="256" />
  </asset>
  <worldbody>
    <light pos="-0.5 -0.3 0.8" dir="0.5 0.3 -0.8" diffuse="0.3 0.3 0.3" />
    <light pos="0.4 -0.5 1.0" dir="-0.4 0.5 -1.0" directional="true" diffuse="0.7 0.7 0.7" />
    <geom name="floor" type="plane" size="1 1 0.01" material="grid" />
    <geom type="mesh" mesh="base_link" />
    <body name="link1_1" pos="-9.9e-05 -0.007243 0.027983">
      <inertial pos="-6.74952e-05 -0.0304904 0.0537666" quat="0.741279 0.0624238 -0.0421672 0.666956" mass="0.241847" diaginertia="0.00020148 0.00019497 9.255e-05" />
      <joint name="base_link_to_link1" pos="0 0 0" axis="0 -0.008727 0.999962" range="-2.0944 2.0944" actuatorfrcrange="-1.5 1.5" damping="0.1" frictionloss="0.05" />
      <geom pos="9.9e-05 0.007243 -0.027983" type="mesh" mesh="link1_1" />
      <body name="link2_1" pos="0.020891 -0.031313 0.091377">
        <inertial pos="-0.0183886 0.0626104 0.00101204" quat="0.487483 0.509946 -0.505248 0.49703" mass="0.986114" diaginertia="0.00163814 0.00133618 0.000430679" />
        <joint name="link1_to_link2" pos="0 0 0" axis="-0.999962 -0.008726 -7.6e-05" range="-3.22886 0.174533" actuatorfrcrange="-1.5 1.5" damping="0.1" frictionloss="0.05" />
        <geom pos="-0.020792 0.038556 -0.11936" quat="1 0 0 0" type="mesh" mesh="link2_1" />
        <body name="link3_1" pos="0.00151 0.112435 0.029417">
          <inertial pos="-0.0177515 -0.0654403 -0.000172961" quat="0.496869 0.499452 -0.493993 0.509548" mass="0.903115" diaginertia="0.0014402 0.00119426 0.000363546" />
          <joint name="link2_to_link3" pos="0 0 0" axis="-0.999924 -0.00865 -0.008802" range="0 3.31613" actuatorfrcrange="-1.5 1.5" damping="0.1" frictionloss="0.05" />
          <geom pos="-0.022302 -0.073879 -0.148777" quat="1 0 0 0" type="mesh" mesh="link3_1" />
          <body name="link4_1" pos="0.00208 -0.134461 0.00412">
            <inertial pos="-0.0143886 -0.0288027 -0.000205619" quat="0.220056 0.668013 -0.224508 0.674485" mass="0.317735" diaginertia="0.000239011 0.000171595 0.000119394" />
            <joint name="link3_to_link4" pos="0 0 0" axis="-0.999848 0.000153 -0.017451" range="-1.65806 1.65806" actuatorfrcrange="-1.5 1.5" damping="0.1" frictionloss="0.05" />
            <geom pos="-0.024382 0.060582 -0.152897" quat="1 0 0 0" type="mesh" mesh="link4_1" />
            <body name="link5_1" pos="-0.01732 -0.060045 -0.000831">
              <inertial pos="0 -0.01 0.005" quat="1 0 0 0" mass="0.08" diaginertia="6e-05 6e-05 4e-05" />
              <joint name="link4_to_link5" pos="0 0 0" axis="-1e-06 0.999961 0.008803" range="-4.27606 1.5708" actuatorfrcrange="-1.5 1.5" damping="0.1" frictionloss="0.05" />
              <body name="sg_mount" pos="-0.0014 -0.0477 -0.0002" quat="0.70710678 0.70710678 0 0">
                <include file="gripper_body.xml" />
              </body>
            </body>
          </body>
        </body>
      </body>
    </body>
  </worldbody>
  <actuator>
    <position name="base_link_to_link1" joint="base_link_to_link1" kp="12" kv="2.0" forcerange="-1.5 1.5" />
    <position name="link1_to_link2" joint="link1_to_link2" kp="18" kv="3.0" forcerange="-1.5 1.5" />
    <position name="link2_to_link3" joint="link2_to_link3" kp="14" kv="2.33" forcerange="-1.5 1.5" />
    <position name="link3_to_link4" joint="link3_to_link4" kp="8" kv="1.33" forcerange="-1.5 1.5" />
    <position name="link4_to_link5" joint="link4_to_link5" kp="6" kv="1.0" forcerange="-1.5 1.5" />
  </actuator>
  <include file="gripper_actuation.xml" />
  <contact>
    <exclude body1="link5_1" body2="slide_gripper_base" />
    <exclude body1="world" body2="link1_1" />
  </contact>
</mujoco>

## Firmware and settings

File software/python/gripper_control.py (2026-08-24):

#!/usr/bin/env python3
"""
Parallel Gripper Control Software
=================================

Professional control software for the open-source parallel gripper using
Feetech STS3215 servo motors. Provides real-time control, monitoring, and
feedback for robotics applications.

Features:
- Precise position control with degree-based input
- Real-time monitoring (position, current, voltage, temperature, load)
- Cross-platform compatibility (Windows, Linux, macOS)
- Interactive control interface
- Comprehensive error handling

Requirements:
- STServo SDK (https://github.com/FEETECH-RC/STServo_SDK_Python)
- Python 3.6+
- Serial communication interface

Author: Robonine (https://robonine.com)
License: Apache-2.0

Portions of this file were contributed while it was offered under the MIT
Licence; those contributions are relicensed here under Apache-2.0 with the
contributor's agreement. See RELICENSING.md.
"""

# SPDX-FileCopyrightText: Copyright (c) 2025 Robonine
# SPDX-License-Identifier: Apache-2.0

import logging
import os
import sys
import time
from pathlib import Path
from typing import Optional, Tuple

import serial.tools.list_ports

# Cross-platform keyboard input handling
if os.name == 'nt':
    import msvcrt
    def getch():
        """Get single character input (Windows)"""
        return msvcrt.getch().decode()
else:
    import termios
    import tty
    def getch():
        """Get single character input (Unix/Linux/macOS)"""
        fd = sys.stdin.fileno()
        old_settings = termios.tcgetattr(fd)
        try:
            tty.setraw(fd)
            return sys.stdin.read(1)
        finally:
            termios.tcsetattr(fd, termios.TCSADRAIN, old_settings)

# Graceful SDK path handling using pathlib
sdk_path = Path(__file__).resolve().parent.parent / "STservo_sdk"
sys.path.append(str(sdk_path))

try:
    from STservo_sdk import *
except ImportError:
    print("Error: STServo SDK not found!")
    print("Please install STServo SDK from: https://github.com/FEETECH-RC/STServo_SDK_Python")
    print("Copy the STservo_sdk folder to your project directory or Python path.")
    sys.exit(1)

# Dynamic COM port selection
print("\n🔌 Available COM ports:")
ports = list(serial.tools.list_ports.comports())
if not ports:
    print("❌ No COM ports found. Please connect your device and try again.")
    sys.exit(1)
for idx, port in enumerate(ports):
    print(f"  [{idx}] {port.device}")

choice = input("Select port number (default 0): ").strip()
SELECTED_PORT = ports[int(choice)].device if choice.isdigit() and int(choice) < len(ports) else ports[0].device

# Configuration Constants
class GripperConfig:
    """Configuration parameters for the parallel gripper"""

    # Servo Configuration
    STS_ID = 1                  # Servo ID (can be changed if multiple servos)
    BAUDRATE = 1000000         # Communication baud rate (1 Mbps)
    DEVICENAME = SELECTED_PORT  # Dynamic port from user selection

    # Motion Parameters
    MAX_DEGREE = 360           # Maximum rotation (degrees)
    MAX_POSITION = 4095        # Maximum position value (12-bit resolution)
    DEFAULT_SPEED = 4800       # Default movement speed
    DEFAULT_ACCELERATION = 5   # Default acceleration

    # Monitoring Parameters
    LSB_TO_mA = 2700 / 2047   # Current conversion factor (~1.32 mA per LSB)
    VOLTAGE_SCALE = 0.1       # Voltage scale factor (0.1V per LSB)
    LOAD_SCALE = 100 / 2047   # Load percentage scale factor

    # Safety Limits
    MAX_TEMPERATURE = 70      # Maximum safe temperature (°C)
    MAX_CURRENT = 2000        # Maximum safe current (mA)

    # Update Intervals
    MONITOR_INTERVAL = 0.05   # Monitoring update interval (seconds)

class ParallelGripper:
    """
    Main class for controlling the parallel gripper

    Provides high-level interface for gripper control, monitoring, and safety.
    """

    def __init__(self, config: GripperConfig = None):
        """
        Initialize the gripper controller

        Args:
            config: Configuration object (uses default if None)
        """
        self.config = config or GripperConfig()
        self.port_handler = None
        self.packet_handler = None
        self.is_connected = False

        # Setup logging
        logging.basicConfig(level=logging.INFO,
                          format='%(asctime)s - %(levelname)s - %(message)s')
        self.logger = logging.getLogger(__name__)

    def connect(self) -> bool:
        """
        Establish connection to the servo

        Returns:
            bool: True if connection successful, False otherwise
        """
        try:
            self.port_handler = PortHandler(self.config.DEVICENAME)
            self.packet_handler = sts(self.port_handler)

            if not self.port_handler.openPort():
                self.logger.error(f"Failed to open port {self.config.DEVICENAME}")
                return False

            if not self.port_handler.setBaudRate(self.config.BAUDRATE):
                self.logger.error(f"Failed to set baud rate to {self.config.BAUDRATE}")
                return False

            # Set servo to position control mode
            self.packet_handler.write1ByteTxRx(self.config.STS_ID, 33, 0)

            self.is_connected = True
            self.logger.info(f"Connected to servo ID {self.config.STS_ID} on {self.config.DEVICENAME}")
            return True

        except Exception as e:
            self.logger.error(f"Connection failed: {e}")
            return False

    def disconnect(self):
        """Close the connection to the servo"""
        if self.port_handler and self.is_connected:
            self.port_handler.closePort()
            self.is_connected = False
            self.logger.info("Disconnected from servo")

    def degrees_to_position(self, degrees: float) -> int:
        """
        Convert degrees to servo position value

        Args:
            degrees: Angle in degrees (can be negative)

        Returns:
            int: Servo position value (0-4095)
        """
        degrees = degrees % self.config.MAX_DEGREE
        return int((degrees / self.config.MAX_DEGREE) * self.config.MAX_POSITION)

    def position_to_degrees(self, position: int) -> float:
        """
        Convert servo position value to degrees

        Args:
            position: Servo position value (0-4095)

        Returns:
            float: Angle in degrees
        """
        return (position / self.config.MAX_POSITION) * self.config.MAX_DEGREE

    def move_to_angle(self, angle: float, speed: int = None, acceleration: int = None) -> bool:
        """
        Move gripper to specified angle

        Args:
            angle: Target angle in degrees
            speed: Movement speed (uses default if None)
            acceleration: Movement acceleration (uses default if None)

        Returns:
            bool: True if command sent successfully, False otherwise
        """
        if not self.is_connected:
            self.logger.error("Not connected to servo")
            return False

        speed = speed or self.config.DEFAULT_SPEED
        acceleration = acceleration or self.config.DEFAULT_ACCELERATION

        goal_position = self.degrees_to_position(angle)

        try:
            result, error = self.packet_handler.WritePosEx(
                self.config.STS_ID, goal_position, speed, acceleration
            )

            if result != COMM_SUCCESS:
                self.logger.error(f"Communication error: {self.packet_handler.getTxRxResult(result)}")
                return False

            if error != 0:
                self.logger.error(f"Servo error: {self.packet_handler.getRxPacketError(error)}")
                return False

            self.logger.info(f"Moving to {angle:.1f}° (position {goal_position})")
            return True

        except Exception as e:
            self.logger.error(f"Move command failed: {e}")
            return False

    def get_status(self) -> Optional[dict]:
        """
        Get current servo status and telemetry

        Returns:
            dict: Status information or None if error
        """
        if not self.is_connected:
            return None

        try:
            # Current position
            position, _, _ = self.packet_handler.ReadPos(self.config.STS_ID)
            degrees = self.position_to_degrees(position)

            # Current draw
            current_raw, _, _ = self.packet_handler.read2ByteTxRx(self.config.STS_ID, 69)
            current = self.packet_handler.sts_tohost(current_raw, 15)
            current_mA = current * self.config.LSB_TO_mA

            # Supply voltage
            voltage_raw, _, _ = self.packet_handler.read1ByteTxRx(self.config.STS_ID, 62)
            voltage = voltage_raw * self.config.VOLTAGE_SCALE

            # Load percentage
            load_raw, _, _ = self.packet_handler.read2ByteTxRx(self.config.STS_ID, 60)
            load_percent = int(round(load_raw * self.config.LOAD_SCALE))

            # Temperature
            temperature, _, _ = self.packet_handler.read1ByteTxRx(self.config.STS_ID, 63)

            # Movement status
            is_moving, _, _ = self.packet_handler.ReadMoving(self.config.STS_ID)

            return {
                'position': position,
                'degrees': degrees,
                'current_raw': current,
                'current_mA': current_mA,
                'voltage': voltage,
                'load_percent': load_percent,
                'temperature': temperature,
                'is_moving': bool(is_moving)
            }

        except Exception as e:
            self.logger.error(f"Status read failed: {e}")
            return None

    def wait_for_completion(self, target_position: int, timeout: float = 10.0) -> bool:
        """
        Wait for movement to complete with real-time monitoring

        Args:
            target_position: Expected final position
            timeout: Maximum wait time in seconds

        Returns:
            bool: True if movement completed successfully
        """
        start_time = time.time()

        print("🟡 Movement in progress... (Press Ctrl+C to stop)\n")

        try:
            while time.time() - start_time < timeout:
                time.sleep(self.config.MONITOR_INTERVAL)

                status = self.get_status()
                if not status:
                    return False

                # Display status
                print(f" → Target: {target_position:4d} | "
                      f"Position: {status['position']:4d} ({status['degrees']:6.1f}°) | "
                      f"Current: {status['current_raw']:3d} ({status['current_mA']:.0f}mA) | "
                      f"Load: {status['load_percent']:2d}% | "
                      f"Temp: {status['temperature']}°C")

                # Safety checks
                if status['temperature'] > self.config.MAX_TEMPERATURE:
                    self.logger.warning(f"High temperature: {status['temperature']}°C")

                if status['current_mA'] > self.config.MAX_CURRENT:
                    self.logger.warning(f"High current: {status['current_mA']:.0f}mA")

                # Check if movement completed
                if not status['is_moving']:
                    print("✅ Movement completed\n")
                    return True

            self.logger.warning("Movement timeout")
            return False

        except KeyboardInterrupt:
            print("\n⏹️ Movement interrupted by user")
            return False

    def interactive_control(self):
        """Run interactive control interface"""
        print("\n" + "="*60)
        print("🤖 PARALLEL GRIPPER CONTROL INTERFACE")
        print("="*60)
        print(f"Servo ID: {self.config.STS_ID}")
        print(f"Port: {self.config.DEVICENAME}")
        print(f"Baud Rate: {self.config.BAUDRATE}")
        print("-"*60)
        print("Commands:")
        print("  • Enter angle in degrees (positive or negative)")
        print("  • Press Enter (empty) to exit")
        print("  • Ctrl+C to interrupt movement")
        print("="*60)

        try:
            while True:
                user_input = input("\nEnter target angle (degrees): ").strip()

                if not user_input:
                    print("👋 Exiting...")
                    break

                try:
                    angle = float(user_input)
                    target_position = self.degrees_to_position(angle)

                    if self.move_to_angle(angle):
                        self.wait_for_completion(target_position)

                except ValueError:
                    print("❌ Invalid input. Please enter a number.")
                except Exception as e:
                    self.logger.error(f"Control error: {e}")

        except KeyboardInterrupt:
            print("\n👋 Control interface interrupted")

def main():
    """Main function - entry point for the application"""
    print("🚀 Starting Parallel Gripper Control Software...")

    # Create gripper instance
    gripper = ParallelGripper()

    try:
        # Connect to servo
        if not gripper.connect():
            print("❌ Failed to connect to servo. Please check:")
            print("  • Port name (currently: {})".format(gripper.config.DEVICENAME))
            print("  • Servo power and connections")
            print("  • Servo ID (currently: {})".format(gripper.config.STS_ID))
            print("  • Baud rate (currently: {})".format(gripper.config.BAUDRATE))
            return 1

        # Run interactive control
        gripper.interactive_control()

    except Exception as e:
        print(f"❌ Unexpected error: {e}")
        return 1

    finally:
        # Ensure clean shutdown
        gripper.disconnect()

    return 0

if __name__ == "__main__":
    sys.exit(main())

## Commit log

2026-01-05 feat: Remove obsolete 3D model files: clamp.stl, drive-gear.stl, gear-rack.stl, main-frame.stl, and gripper.step
    [Follower gripper (table 180x180).STL, RB9.01.060.015 Main frame 128mm (follower).STL, RB9.01.060.021 Clamp.STL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]
2026-01-05 docs: Revise Bill of Materials (BOM) to streamline component listing and update supplier links
2026-01-05 docs: Revise Bill of Materials to categorize components, update pricing, and enhance supplier links
2026-01-05 docs: Remove README.md for 3D models of the parallel gripper
2026-01-05 docs: Update assembly guide for Follower Gripper SO-ARM101, including component changes and revised assembly steps; remove obsolete images
2026-01-07 docs: Update Bill of Materials for Amazon, replacing servo motor model and adjusting total costs
2026-01-07 feat: Add new assembly images and update paths in assembly guide
2026-01-07 docs: Revise technical specifications for SO ARM 100/101 Parallel Gripper, including detailed performance metrics, dimensions, and camera compatibility
2026-01-07 docs: Add Step 9 for Gripper Holder Attachment in assembly guide, including components and detailed instructions
2026-01-07 docs: Revise Quick Start Guide for Follower Gripper SO-ARM101, updating component lists, assembly steps, and troubleshooting sections
2026-01-07 docs: Update assembly guide for Follower Gripper SO-ARM101, refining assembly steps and enhancing troubleshooting guidance
2026-01-07 docs: Add image and caption to Quick Start Guide for Follower Gripper SO-ARM101, enhancing visual engagement
2026-01-07 docs: Update Quick Start Guide for Follower Gripper SO-ARM101, enhancing the image caption with a direct link to the video
2026-01-07 docs: Revise README.md for SO-ARM100/101 Parallel Gripper, enhancing project overview, key features, specifications, and camera compatibility sections; update images and links for better clarity and 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
2026-01-07 docs: Update README and model documentation for Follower Gripper, enhancing compatibility details for 3D printers, renaming STL files for clarity, and removing obsolete model files
    [Follower_Gripper_180x180_BedSize.STL]
2026-01-31 docs(bom): remove Round Rod D6x150, Threaded Rod M3x150, and Screw M4x6
2026-01-31 docs(bom): fix broken Amazon links for rods and fasteners
2026-01-31 docs(bom): rename bom-amazon.md to bom.md and update broken links
2026-07-14 Document histology slide gripper fork
    [microscope-slide-camera-holder-arducam.step, microscope-slide-camera-holder-arducam.stl, microscope-slide-clamp-1.step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]
2026-07-22 add PDF assembly guides for gripper and SO-ARM101 arm
2026-07-25 Update microscope slide gripper CAD
    [microscope-slide-camera-holder-arducam.step, microscope-slide-camera-holder-arducam.stl, microscope-slide-clamp-1.step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]
2026-08-03 Update microscope slide gripper CAD assets
    [the-parallel-microscope-slide-gripper.step, the-parallel-microscope-slide-gripper.stl]
2026-08-08 Rework histology mod as community add-on section
    - Restore original project title, hero image, and YouTube demo link
    - Present the histology slide gripper as a community mod section
    instead of rebranding the repository as a fork
    - Consolidate histology photos and CAD renders in one section
    - Remove 25 MB demo GIF from the repo; link the LinkedIn demo instead
2026-08-08 Move histology mod into community/histology-slide-gripper/
    - All mod files (README, photos, demo GIF, STL/STEP) now live in one
    self-contained directory under community/
    - Restore original README, docs/bom.md, and models/README.md; main README
    links to the mod via a short Community Mods section
    - Restore the demo GIF inside the mod's assets/
    [the-parallel-microscope-slide-gripper.step, the-parallel-microscope-slide-gripper.stl]
2026-08-23 Add MuJoCo simulation for histology slide gripper
    [base.stl, base_link.stl, clamp_1.stl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]
2026-08-23 Fix MuJoCo lint issues
    [so101_slide_gripper.xml, so_101_arm.urdf]
2026-08-24 Relicense: GPL-3.0 -> CERN-OHL-P-2.0 / Apache-2.0 / CC BY 4.0
    GPL-3.0 is written for software. Its definitions of "source code" and
    "Corresponding Source" do not map onto a physical object, so for the CAD
    half of this project it was never clear what actually triggered the
    licence's obligations. This splits the repository three ways:
    Hardware / CAD CERN-OHL-P-2.0
    Software Apache-2.0
    Documentation and images CC BY 4.0
    The map lives in LICENSE (human-readable) and REUSE.toml (machine-readable,
    enforced by `reuse lint` in pre-commit and therefore in CI). Full licence
    texts in LICENSES/.
    Fixes several licensing defects found along the way:
    - No copyright hol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
    [gripper_control.py]
2026-08-24 Track .gitignore and CLAUDE.md; ignore editor and Python artefacts
    Both files existed on disk but were never tracked, so every clone started
    without them and `git add -A` kept sweeping up build artefacts.
    CLAUDE.md is updated for the new licensing: it now describes the three-way
    split and states that new files must be covered by REUSE.toml.
    .gitignore additionally ignores .vscode/ (editor config, deliberately not
    shared) and Python artefacts — __pycache__/, *.py[cod], .pytest_cache/ —
    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

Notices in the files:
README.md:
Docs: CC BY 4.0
